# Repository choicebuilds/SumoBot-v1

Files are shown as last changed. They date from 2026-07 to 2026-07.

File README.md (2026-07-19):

# SumoBot v1
Two weeks - that was the time I had to go from absolutely nothing to a fully-functioning robot to participate in the upcoming competition in Orlando, Florida. At the time, it took JLCPCB 4 weeks to ship a PCB to the US even with rushed shipping due to delayed customs; so, I decided to make everything inside our makerspace - The Hive.
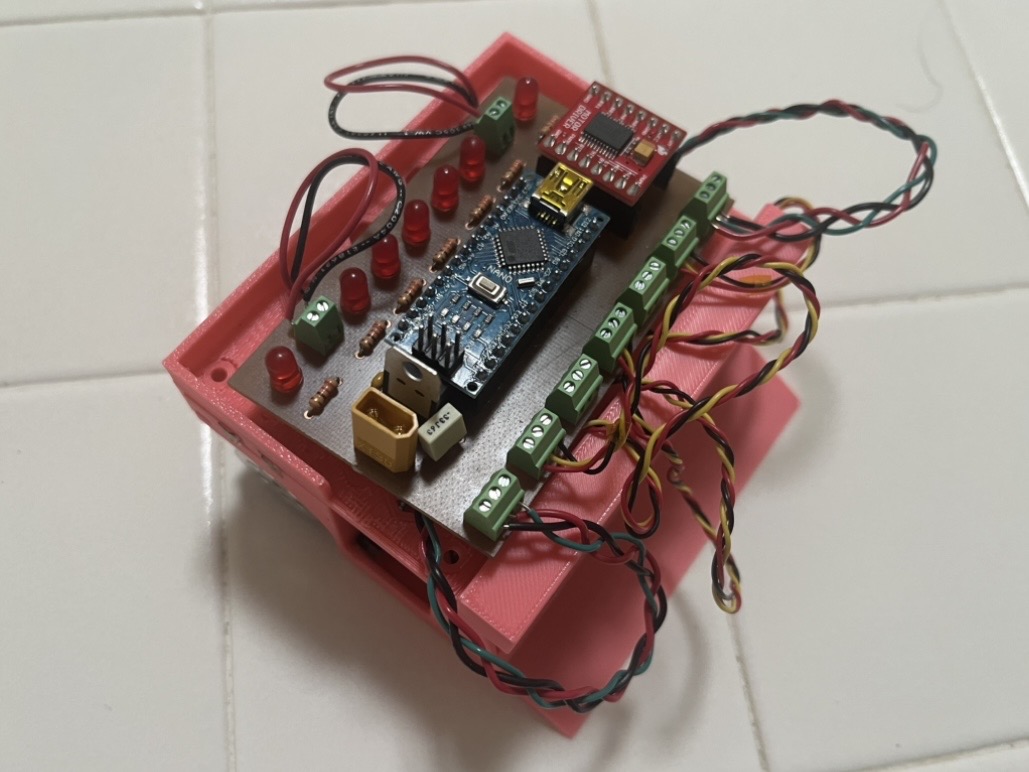
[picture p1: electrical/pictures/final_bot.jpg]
SumoBot
  
Thanks to my wonderful peers and the knowledge gained throughout my time at Georgia Tech, I learned how to use KiCAD, fabricate the PCB using the LPKF Protomat/Protolaser, and through-hole solder all the components. The chassis of the robot was designed by a wonderful teammate on the mechanical side. This version was merely a rushed proof of concept for the upcoming competition (if you read on, you will see the various limitations I faced and how I combatted them for the time being). A significantly more complex, 4-layer PCB that addressed all the issues along with quality of life updates have been created the following semester: [SumoBot v2](https://github.com/choicebuilds/SumoBot-v2)!

## Schematic
Since I only had two weeks, my goal was to add only the bare minimum components for a functional robot. This consisted of a distance sensor to detect the other sumobot, a line sensor to detect whether we were out of bounds or not, a motor driver to drive the wheels, a power system, and status LEDs for debugging. The arduino nano was small and sufficient for my needs; here is my very first schematic:  
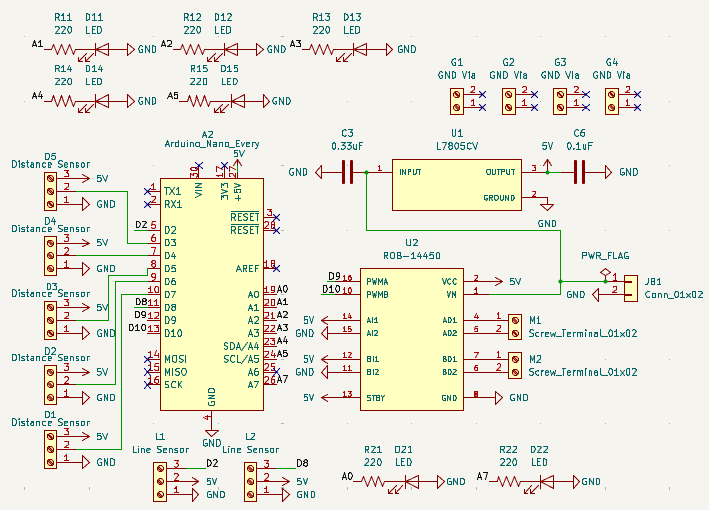
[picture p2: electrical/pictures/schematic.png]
Schematic
  
With the distance sensors and line sensors being abstracted as an attachable module, it was easy to determine which footprints to use since it was either a screw terminal to attach said sensors or female pins to insert the arduino and the motor driver. However, the only issue was power. While I could have used a buck converter, I figured for simplicity sake, I would use a MOSFET that basically dissipated excess voltage into heat, allowing it to supply 5V to the entire system. The advantage here was that I could actually connect the battery's 9V directly into the motors so that while the system got the 5V it needed, the motors could go overdrive at 9V.  
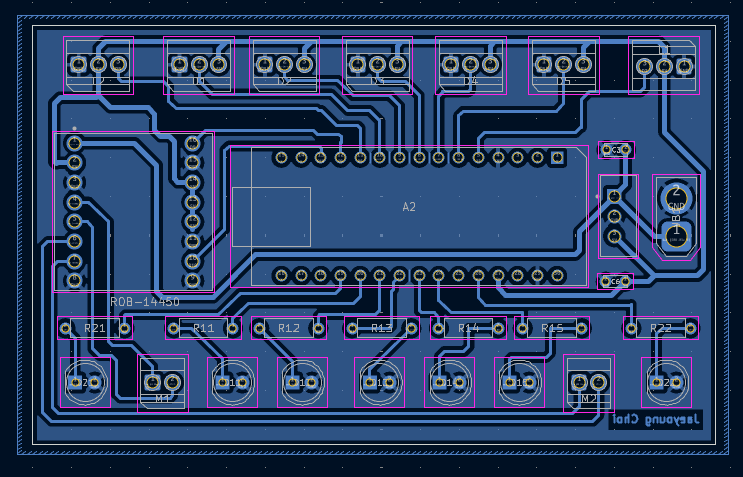
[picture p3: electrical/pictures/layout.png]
Layout


### Issue #1
This is where I ran into my first issue: as simple as the Arduino Nano was to use, if I hogged 7 pins for status LEDs (5 for distance and 2 for line), I ran out of GPIO pins to use for the motor driver. Considering I had two weeks left, I did not have a time to come up with a complex strategy. So, I just tied AI1 and BI1 to 5V and AI2 and BI2 to GND (along with STBY to 5V), which saved me THREE pins. The only drawback was the fact that I could not move backwards; however, depending on the values of PWMA (left motor) and PWMB (right motor), I could control the speed and spin around as needed.  
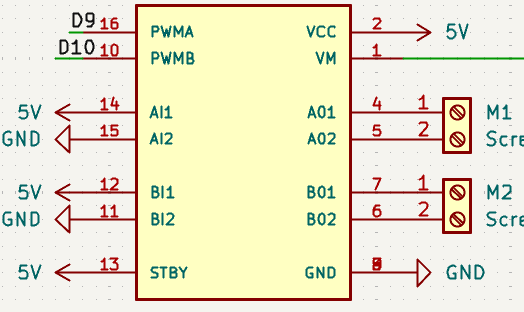
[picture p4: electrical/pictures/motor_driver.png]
Motor Schematic


## Fabrication
While I found it super cool that I could literally fabricate a PCB inside our makerspace, I soon figured out why nobody actually used the machines: it was plagued with a lot of limitations and lack of experience. Considering the fact that none of the peer instructors (other than one passionate master PI who I cannot thank enough) knew how to use the machines and I only had a book to go off of, I ran into a lot of minor inconveniences and setbacks. However, I will filter out the noise and only highlight the limitations of the final product (i.e. I won't get into nontechnical issues such as alignment as shown below):  
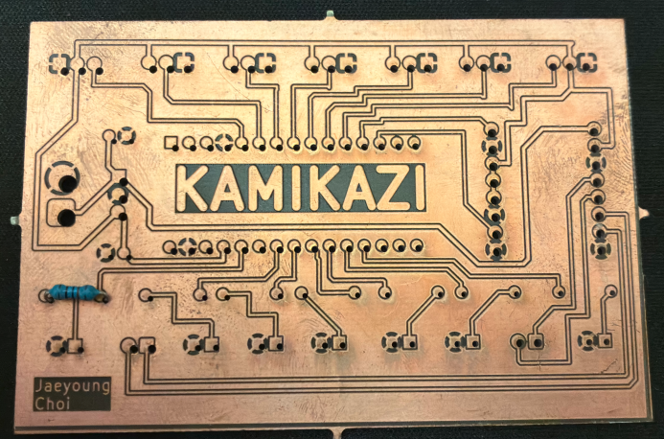
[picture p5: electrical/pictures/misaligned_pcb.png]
Misaligned PCB


### Issue #2
While the LPKF Protomat and Protolaser could technically make a functional PCB, there was no way to make vias (non-plated drilling). In other words, I could not connect the front layer to the back layer unless I manually connected them via soldering both sides with a wire, which turned out to be a very big inconvenience. So, I had to connect all my traces from VCC to GND to all GPIO pins into the back layer so that when I through-hole soldered everything, the objects would be on the top layer and the soldering will all be done on the bottom layer. Keep in mind, the places where I placed screw terminals and female connectors pins were physically obstructed by the object itself, so if I ever wanted to connect layer 1 to layer 2, I had to create vias to the side, as shown in one of my failed iterations:  
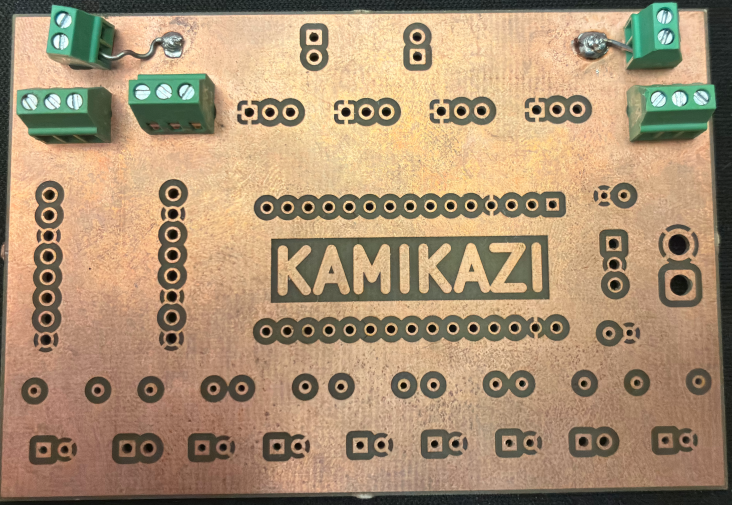
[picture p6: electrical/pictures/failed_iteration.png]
Failed Iteration PCB


### Issue #3
Now you may be wondering: aren't PCBs usually green? Well, that's because my PCBs lacked a solder mask since our makerspace did not have a machine to create them; that also included silkscreens so I had to physically laser out the copper using the laser of the LPKF Protolaser for any text. This made it an absolute nightmare for continuity testing because I kept getting shorts to the GND plane, which was on the same layer as all my connections.  
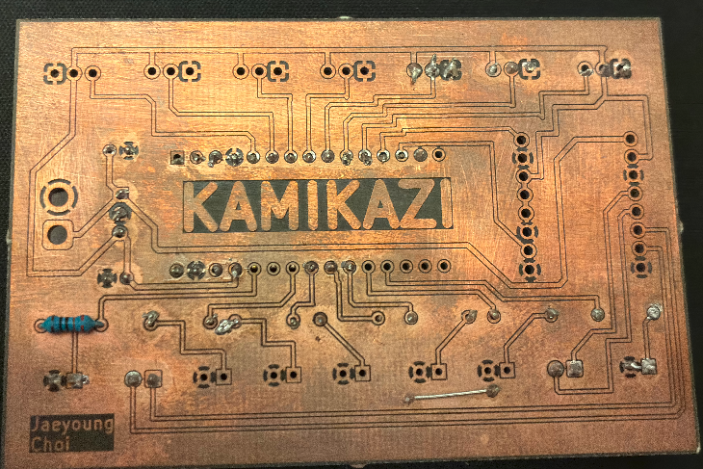
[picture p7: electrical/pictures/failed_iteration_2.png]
Failed Iteration 2 PCB


### Issue #4
This is more of an advanced topic that didn't detrimentally affect the robot, but considering my PCB virtually had zero decoupling capacitors and no dedicated power planes, the whole power network was more susceptible to power supply noise and EMI. Luckily, I did create a ground pour on the unused area and tried to connect a few wires into the other layer for a giant GND plane for heat dissipation on the motors, it was by no means optimal. This issue was fixed during my second iteration in SumoBot v2, but this really was just a proof of concept in the end. Not to mention, 90 degrees traces weren't exactly good practice due to impedance discontinuities, while negligible for my use robot:  
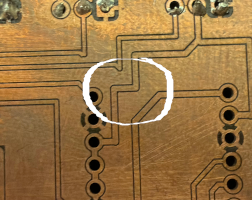
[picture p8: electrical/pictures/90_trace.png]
90 Degree Traces


### Issue #5
Also, A7 is an analog input only pin. While it doesn't affect functionality, you would not see the LED flash.

## The Actual Process
Now fabrication is actually very simple: you import you gerber files (front layer copper layout, back layer copper layout, edge cuts, and drill files) and use the LPKF Protomat to drill the holes:  
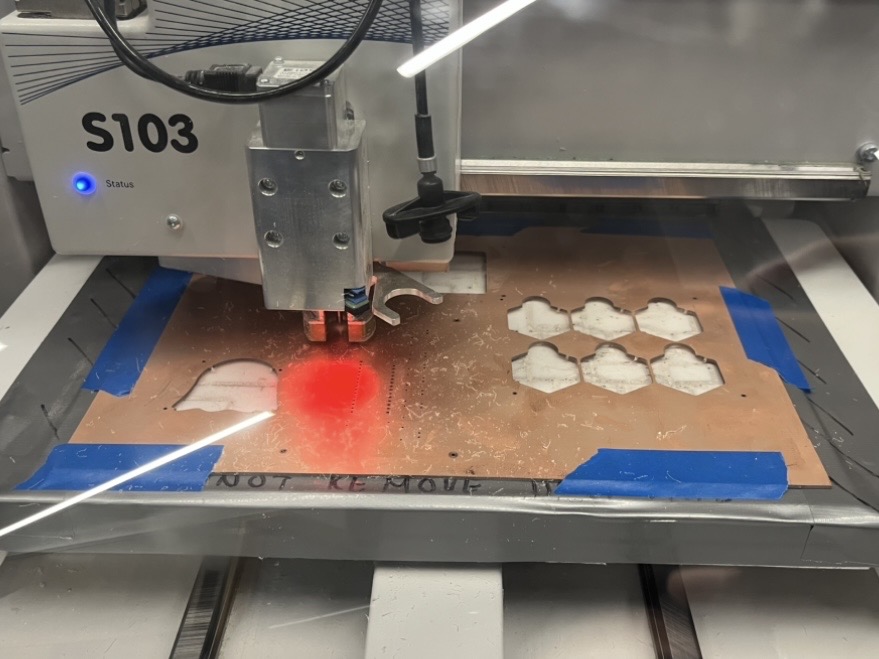
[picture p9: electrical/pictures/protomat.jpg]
LPKF Protomat
  
Then you remove the unwanted copper using the LPKF Protolaser:  
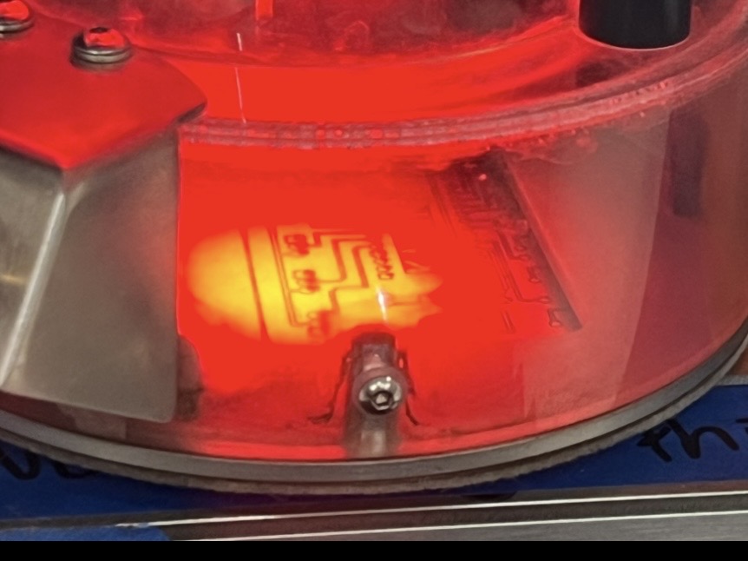
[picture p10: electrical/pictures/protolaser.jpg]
LPKF Protolaser
  
And back to the LPKF Protomat to cut out the board itself from the bigger sheet of copper:  
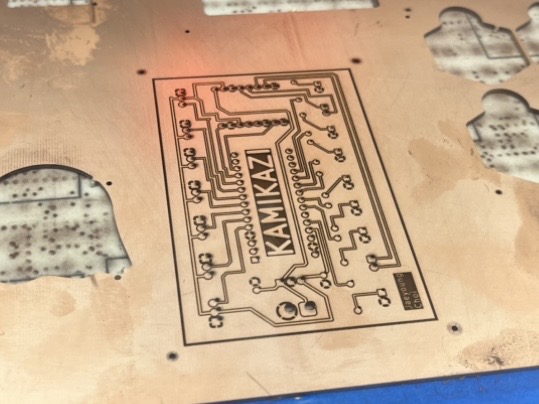
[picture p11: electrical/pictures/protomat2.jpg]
LPKF Protomat 2
  
Thanks to many failed iterations that allowed me to practice soldering, I was able to complete the board! With careful continuity testing, it was ready to be mounted onto the mechanical chassis.  
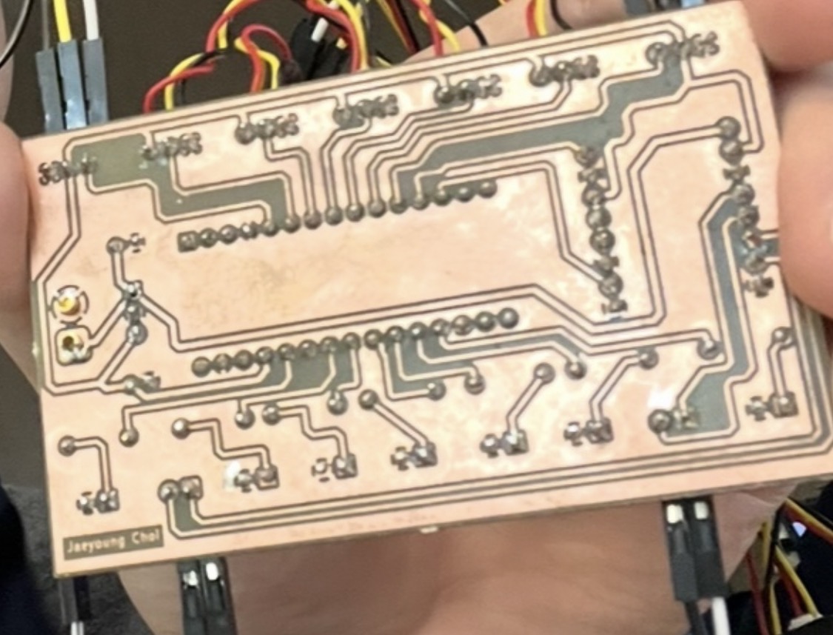
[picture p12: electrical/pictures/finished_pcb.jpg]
Final PCB


## Mechanical & Firmware
Our makerspace had a plethora of 3D printers. One freshman mechanical teammate was diligent and ambitious enough to create the chassis for us in the limited time that we had; here is are a few pictures:  
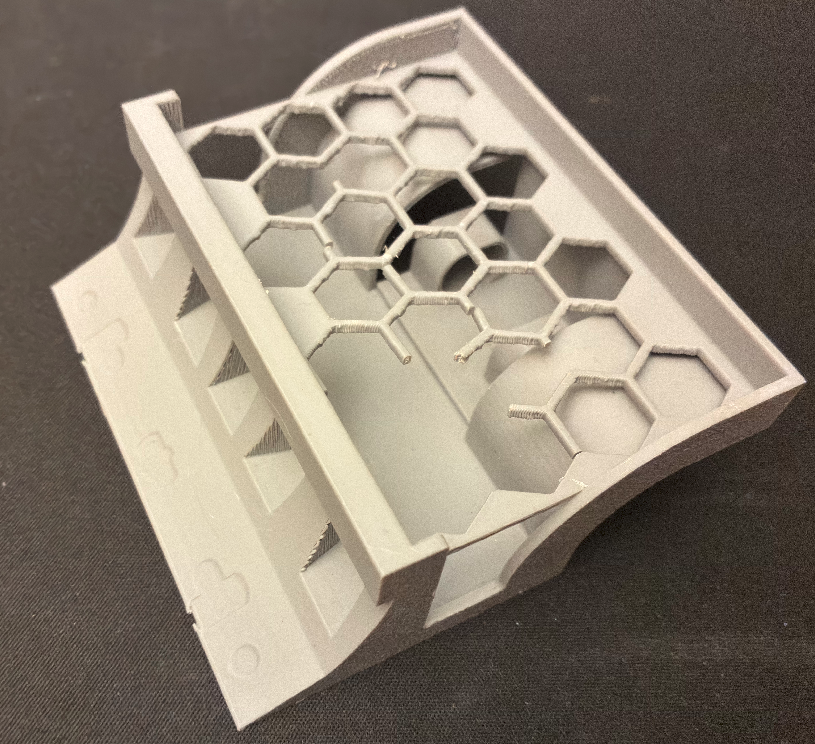
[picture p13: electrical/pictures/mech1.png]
3D Print 1
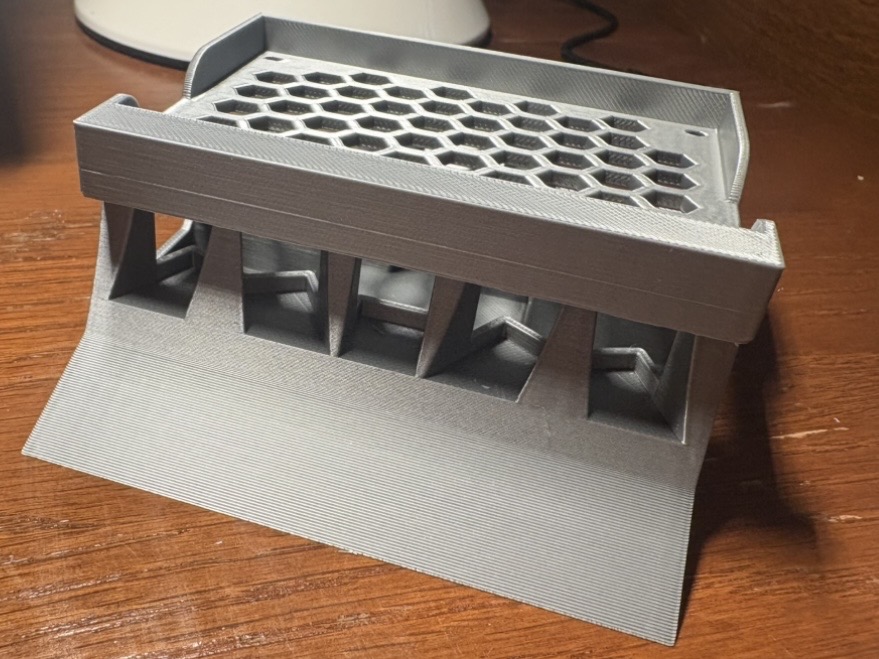
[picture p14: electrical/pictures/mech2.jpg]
3D Print 2
  
Due to it being a public repository, I have only included the basic code for a functional robot. Complex state machines and algorithms used during the competition are excluded.

## Working Demo
While we were a group of five, the whole robot was essentially created by me and the mechanical teammate. Here is a working demo of our robot with my functional PCB:
[](https://www.youtube.com/watch?v=xco6TSbXgns)

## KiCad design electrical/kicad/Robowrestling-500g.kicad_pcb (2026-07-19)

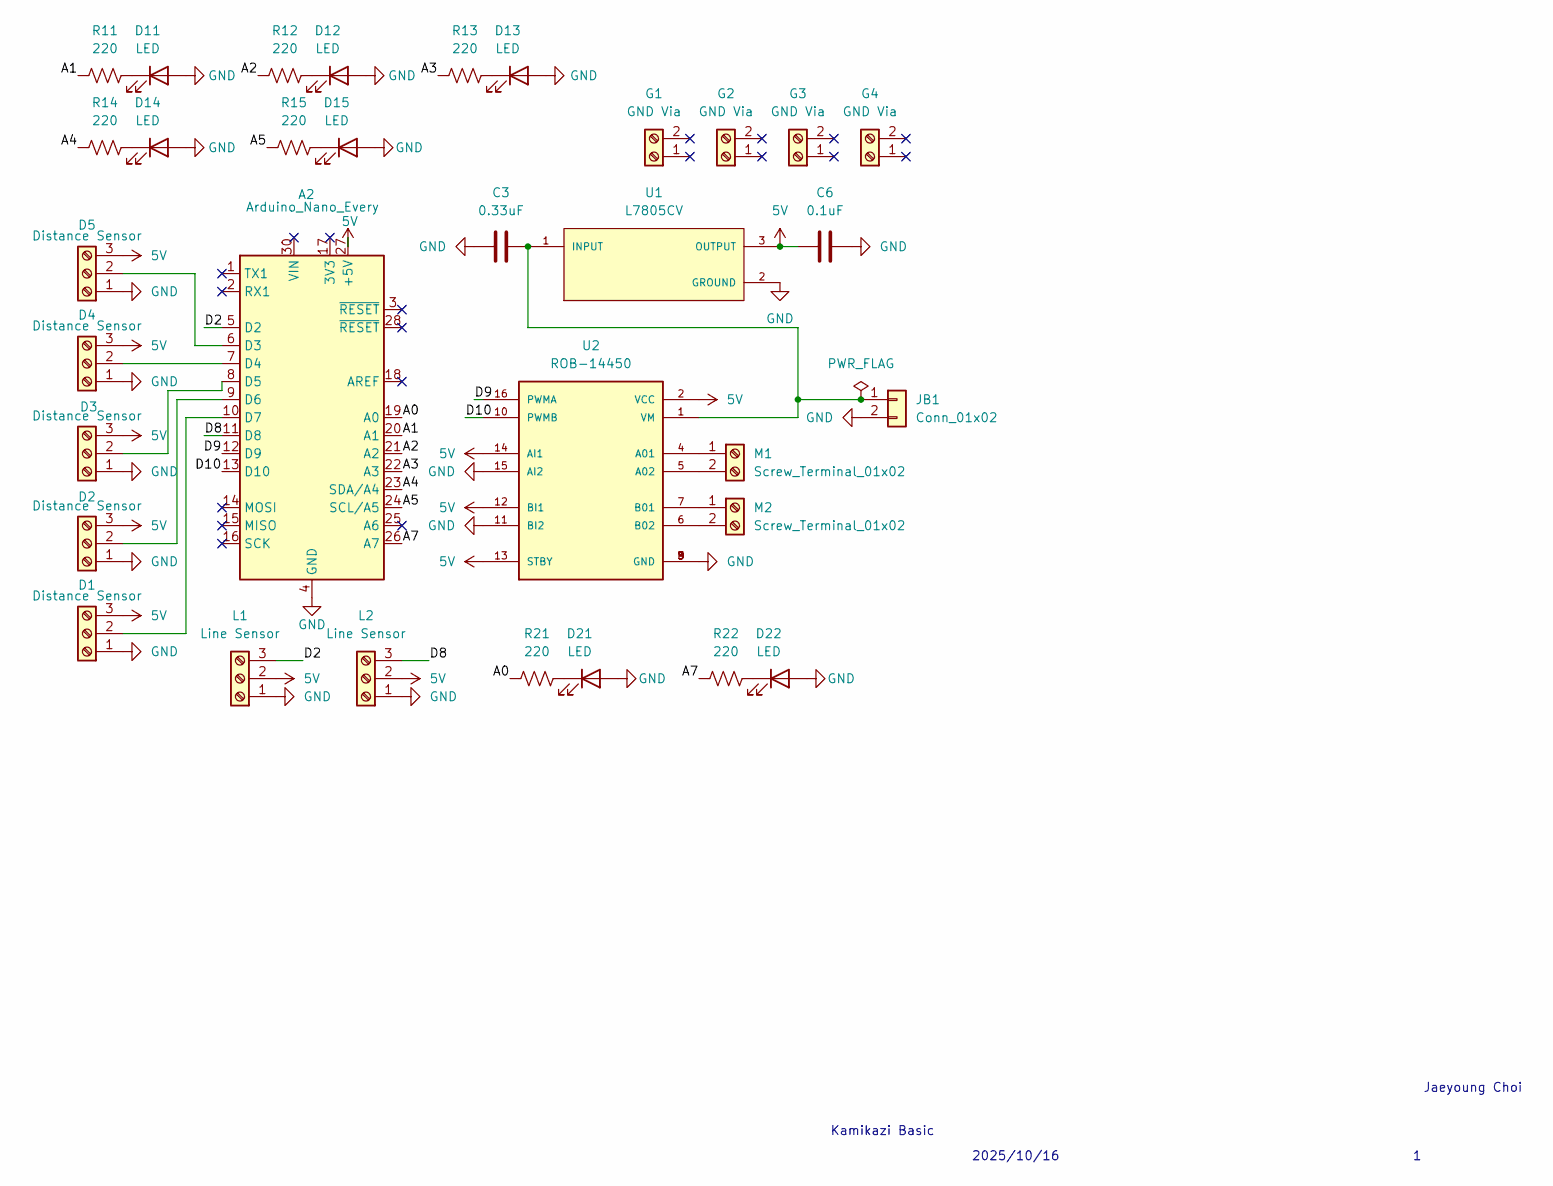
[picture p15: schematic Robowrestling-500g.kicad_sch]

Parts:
A2: Arduino_Nano_Every; Arduino_Nano
C3: 0.33uF; C_Disc_D3.0mm_W1.6mm_P2.50mm
C6: 0.1uF; C_Disc_D3.0mm_W1.6mm_P2.50mm
D1, D2, D3, D4, D5: Distance Sensor; TerminalBlock_Xinya_XY308-2.54-3P_1x03_P2.54mm_Horizontal
D11, D12, D13, D14, D15, D21, D22: LED; LED_D5.0mm
G1, G2, G3, G4: GND Via; TerminalBlock_Xinya_XY308-2.54-2P_1x02_P2.54mm_Horizontal
JB1: Conn_01x02; AMASS_XT30U-F_1x02_P5.0mm_Vertical
L1, L2: Line Sensor; TerminalBlock_Xinya_XY308-2.54-3P_1x03_P2.54mm_Horizontal
M1, M2: Screw_Terminal_01x02; TerminalBlock_Xinya_XY308-2.54-2P_1x02_P2.54mm_Horizontal
R11, R12, R13, R14, R15, R21, R22: 220; R_Axial_DIN0207_L6.3mm_D2.5mm_P7.62mm_Horizontal
U1: L7805CV; TO255P1040X460X1968-3; PARTREV 36
U2: ROB-14450; MODULE_ROB-14450; PARTREV 11-13-17

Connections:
5V: A2.27 (+5V), C6.1, D1.3, D2.3, D3.3, D4.3, D5.3, L1.2, L2.2, U1.3 (OUTPUT), U2.2 (VCC), U2.12 (BI1), U2.13 (STBY), U2.14 (AI1)
/A0: A2.19 (A0), R21.1
/A1: A2.20 (A1), R11.1
/A2: A2.21 (A2), R12.1
/A3: A2.22 (A3), R13.1
/A4: A2.23 (SDA/A4), R14.1
/A5: A2.24 (SCL/A5), R15.1
/A7: A2.26 (A7), R22.1
/D2: A2.5 (D2), L1.3
/D8: A2.11 (D8), L2.3
/D9: A2.12 (D9), U2.16 (PWMA)
/D10: A2.13 (D10), U2.10 (PWMB)
GND: A2.4 (GND), A2.29 (GND), C3.1, C6.2, D1.1, D2.1, D3.1, D4.1, D5.1, D11.2 (A), D12.2 (A), D13.2 (A), D14.2 (A), D15.2 (A), D21.2 (A), D22.2 (A), JB1.2, L1.1, L2.1, U1.2 (GROUND), U2.3 (GND), U2.8 (GND), U2.9 (GND), U2.11 (BI2), U2.15 (AI2)
unnamed: A2.6 (D3), D5.2
unnamed: A2.7 (D4), D4.2
unnamed: A2.8 (D5), D3.2
unnamed: A2.9 (D6), D2.2
unnamed: A2.10 (D7), D1.2
unnamed: D11.1 (K), R11.2
unnamed: D12.1 (K), R12.2
unnamed: D13.1 (K), R13.2
unnamed: D14.1 (K), R14.2
unnamed: D15.1 (K), R15.2
unnamed: D21.1 (K), R21.2
unnamed: D22.1 (K), R22.2
unnamed: C3.2, JB1.1, U1.1 (INPUT), U2.1 (VM)
unnamed: M1.1, U2.4 (A01)
unnamed: M1.2, U2.5 (A02)
unnamed: M2.1, U2.7 (B01)
unnamed: M2.2, U2.6 (B02)

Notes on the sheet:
Kamikazi Basic
Jaeyoung Choi
2025/10/16

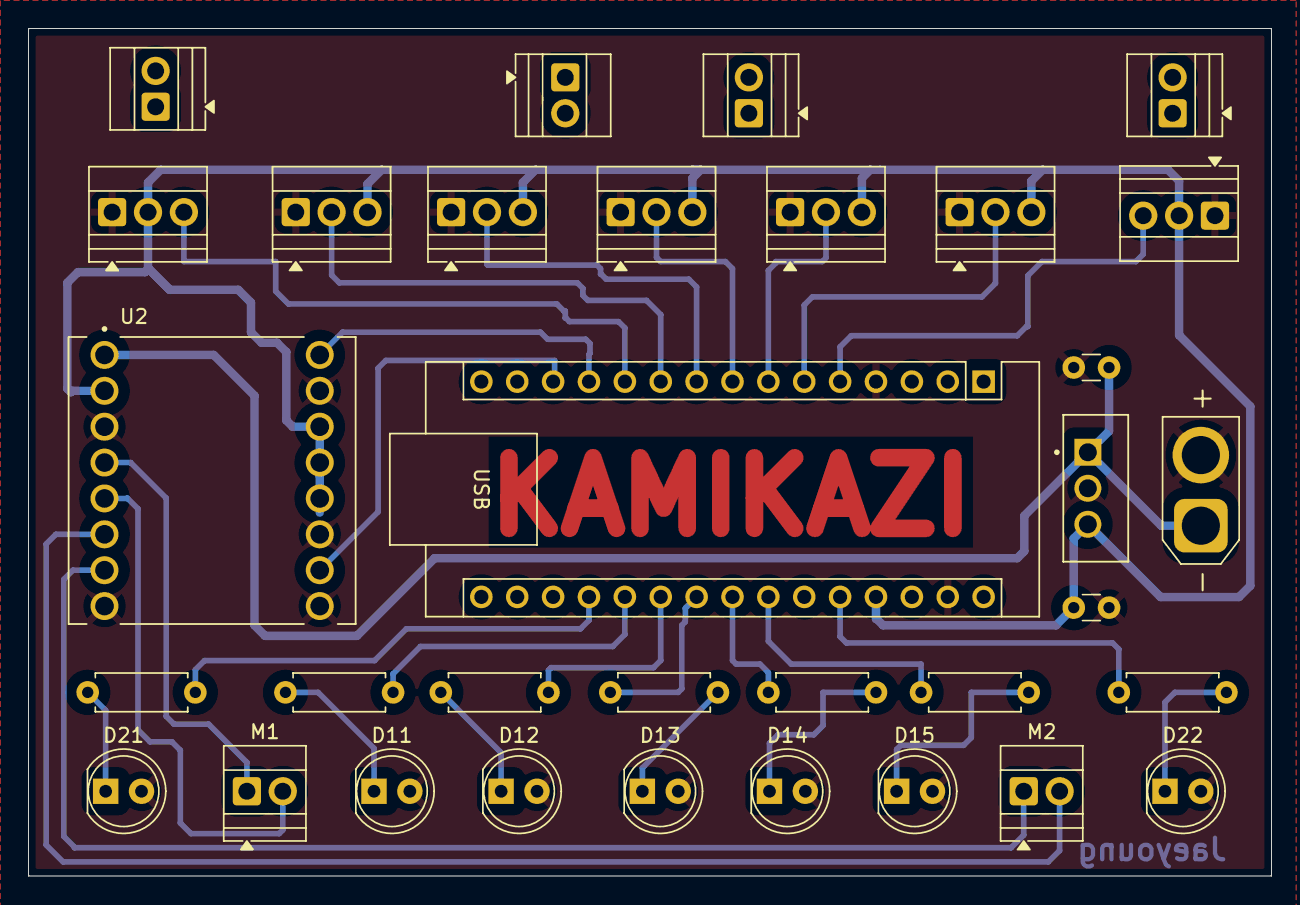
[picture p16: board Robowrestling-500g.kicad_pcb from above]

Board: 4 copper layers, 88.0 x 60.0 mm, 33 parts (0 on the bottom side), 30 nets.

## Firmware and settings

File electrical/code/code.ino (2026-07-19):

const int DS1 = 7;
const int DS2 = 6;
const int DS3 = 5;
const int DS4 = 4;
const int DS5 = 3;
const int LS1 = 8;
const int LS2 = 2;
const int PWMA = 9;
const int PWMB = 10;

const int led1 = A1;
const int led2 = A2;
const int led3 = A3;
const int led4 = A4;
const int led5 = A5;
const int led6 = A0;
const int led7 = A7;

int DValue1;
int DValue2;
int DValue3;
int DValue4;
int DValue5;
int LValue1;
int LValue2;

void setup() {
pinMode(DS1, INPUT);
pinMode(DS2, INPUT);
pinMode(DS3, INPUT);
pinMode(DS4, INPUT);
pinMode(DS5, INPUT);
pinMode(LS1, INPUT);
pinMode(LS2, INPUT);

pinMode(led1, OUTPUT);
pinMode(led2, OUTPUT);
pinMode(led3, OUTPUT);
pinMode(led4, OUTPUT);
pinMode(led5, OUTPUT);
pinMode(led6, OUTPUT);
pinMode(led7, OUTPUT);

pinMode(PWMA, OUTPUT);
pinMode(PWMB, OUTPUT);

Serial.begin(9600);
}

void loop() {
DValue1 = digitalRead(DS1);
DValue2 = digitalRead(DS2);
DValue3 = digitalRead(DS3);
DValue4 = digitalRead(DS4);
DValue5 = digitalRead(DS5);
LValue1 = digitalRead(LS1);
LValue2 = digitalRead(LS2);

DValue1 ? digitalWrite(led1, HIGH) : digitalWrite(led1, LOW);
DValue2 ? digitalWrite(led2, HIGH) : digitalWrite(led2, LOW);
DValue3 ? digitalWrite(led3, HIGH) : digitalWrite(led3, LOW);
DValue4 ? digitalWrite(led4, HIGH) : digitalWrite(led4, LOW);
DValue5 ? digitalWrite(led5, HIGH) : digitalWrite(led5, LOW);

LValue1 ? digitalWrite(led6, LOW) : digitalWrite(led6, HIGH);
LValue2 ? digitalWrite(led7, LOW) : digitalWrite(led7, HIGH);

analogWrite(PWMA, 50);
analogWrite(PWMB, 50);
delay(100);
}
